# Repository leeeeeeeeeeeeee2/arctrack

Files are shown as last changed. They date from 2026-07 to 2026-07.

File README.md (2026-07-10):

# ArcTrack — Model Rocket Flight Computer

**ArcTrack** is a compact flight computer for model rockets. It logs altitude and
motion to a microSD card, reads GPS, and lets you **live-track the rocket over
WiFi** from your phone. v1.3 adds a power LED, buzzer, and servo header for
nose-cone parachute deploy at apogee.

Designed for a **BT-70** body tube with a 3D-printed nose avionics bay.

**Hardware:** bare **ESP32-C3FH4** (QFN-32, 4MB flash) + 2.4 GHz chip antenna,
USB-C, LiPo charger, 3.3 V regulator, BMP280, MPU-6050, microSD, GPS header,
servo + 5 V boost.

> RF note: chip-antenna matching may need tuning. See `hardware/DESIGN.md`.

## Features

- **Altitude** — BMP280 barometer + apogee detection  
- **Motion** — MPU-6050 IMU (launch / burnout)  
- **GPS** — ATGM336H (UART)  
- **Logging** — microSD CSV  
- **Live tracking** — WiFi AP + phone web dashboard  
- **USB-C** — charge + program (native USB)  
- **1S LiPo** — TP4056 charging  
- **Power LED** — on whenever the board is powered  
- **Buzzer** — beeps (apogee / status)  
- **Servo** — parachute / nose deploy at apogee (5 V boost on board)

## Repo layout

| Path | What |
|---|---|
| `hardware/DESIGN.md` | Electrical design, pinout, power, layout |
| `hardware/BOM.md` | Bill of materials |
| `hardware/WIRING.md` | Pin-by-pin wiring |
| `hardware/kicad/` | PCB project (schematic + board) |
| `hardware/gerbers/` | Fabrication outputs (when exported) |
| `firmware/` | PlatformIO firmware for ESP32-C3 |

## PCB / order

1. Read `hardware/DESIGN.md` and `hardware/WIRING.md`
2. Open the project in `hardware/kicad/`
3. Order boards from **JLCPCB** (4-layer, ~70×40 mm). Use Gerbers from `hardware/gerbers/` when present.
4. Hand-solder: GPS module, battery connector, switch, servo header as needed

## Firmware

```bash
cd firmware
pio run                 # build
pio run -t upload       # flash over USB-C
pio device monitor      # serial logs
```

Phone: join WiFi **`ArcTrack`** / password **`launch123`**, open **http://192.168.4.1**

### Pin map (firmware)

| Function | GPIO |
|---|---|
| I2C SDA / SCL | 4 / 5 |
| SD SCK / MOSI / MISO / CS | 6 / 7 / 3 / 10 |
| GPS RX / TX | 20 / 21 |
| Buzzer | 0 |
| Servo PWM | 1 |
| Power LED | hardwired to 3.3 V (not a GPIO) |

## Author

Leighton — UK maker / rocketry + electronics builds.

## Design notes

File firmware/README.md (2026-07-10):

# ArcTrack firmware (ESP32-C3)

PlatformIO project. Matches the ArcTrack PCB pinout in `../hardware/`.

## Build / flash

```bash
pio run
pio run -t upload
pio device monitor
```

## WiFi dashboard

- SSID: `ArcTrack`
- Password: `launch123`
- URL: http://192.168.4.1

## Pins

| Function | GPIO |
|---|---|
| SDA / SCL | 4 / 5 |
| SD SCK / MOSI / MISO / CS | 6 / 7 / 3 / 10 |
| GPS RX / TX | 20 / 21 |
| Buzzer | 0 |
| Servo | 1 |

Tune `servoStow()` / `servoDeploy()` pulse widths in `src/main.cpp` for your nose linkage.

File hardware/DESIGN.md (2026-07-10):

# RocketFC — Hardware Design (bare ESP32-C3FH4 + chip antenna)

Full bare-chip flight computer. Everything the SuperMini gave us for free
(regulator, USB, buttons, reset) is now on our board, plus the RF section
(crystal + antenna + matching). Keep this open while working in KiCad.

> **RF WARNING:** the antenna matching network usually needs tuning to work well,
> ideally with a VNA. To de-risk, copy component **values and layout** from
> Espressif's *ESP32-C3 Hardware Design Guidelines* reference schematic + the
> ESP32-C3-MINI-1 module schematic. Those are the known-good source of truth.

## 0. Main chip

Use **ESP32-C3FH4** (QFN-32, 5×5mm) — it has **4MB flash built in**, so no
external flash chip needed. (ESP32-C3FN4 is the same idea.)

Wire by **pin NAME** using the KiCad symbol — pin numbers vary, names don't.

## 1. Power

```
USB-C VBUS(5V) --> TP4056 --> LiPo(BAT) --> SW1 --> LDO(3.3V) --> +3V3 rail
                     |                                   (ME6211C33 / AMS1117)
                   charge
```

- **USB-C**: VBUS→5V net; GND→GND; D+→GPIO19; D−→GPIO18; CC1,CC2 each 5.1kΩ→GND.
- **TP4056**: IN←VBUS; BAT↔LiPo+; PROG→12kΩ→GND (~100mA); CE→IN; GND→GND.
- **SW1** slide switch: LiPo+ → LDO input (arms logic; charger stays on the cell).
- **LDO**: prefer **ME6211C33M5** (SOT-23-5, 150mV dropout — good at low LiPo V)
  over AMS1117 (1.1V dropout). IN←switched battery; OUT→+3V3; EN→IN; 1µF in, 1µF+
  10µF out.
- Bulk: 10µF on VBUS, 10µF on battery, 22µF on +3V3.

## 2. ESP32-C3FH4 core wiring

### Supply pins (all to +3V3, each with its own 100nF)
- `VDD3P3` (all instances) → +3V3, 100nF each
- `VDD3P3_CPU` → +3V3, 100nF
- `VDD3P3_RTC` → +3V3, 100nF
- `VDDA` / analog VDD3P3 → +3V3 via a **small ferrite bead / 0Ω** for RF cleanliness,
  then 100nF + 10µF (see reference)
- `VDD_SPI` → **1µF to GND** (internal LDO output for in-package flash; do NOT tie
  to 3V3 — follow reference)
- EP (exposed pad) → GND (stitch with vias)

### Enable / reset
- `CHIP_EN` (EN) → 10kΩ pull-up to +3V3, **1µF** to GND (reset RC).
- Optional **RESET button**: EN → button → GND.

### Strapping pins (critical for boot)
- `GPIO2` → 10kΩ pull-up to +3V3 (must be high at boot; keep nothing pulling it low)
- `GPIO8` → 10kΩ pull-up to +3V3 (must be high at boot)
- `GPIO9` → 10kΩ pull-up to +3V3 + **BOOT button** to GND (hold low at reset = flash mode)

### USB (native — no USB-UART chip)
- `GPIO18` → USB_D−
- `GPIO19` → USB_D+
- (optional USBLC6-2 ESD device on D+/D−)

### Clock
- 40 MHz crystal between `XTAL_P` and `XTAL_N`.
- Two load caps to GND (start ~**10–12pF** each; exact value = 2×(CL−Cstray),
  from the crystal datasheet). Some designs also add a small series R (~0Ω).

## 3. RF section (antenna + matching) — copy the reference!

- `LNA_IN` (RF pin) → **pi-matching network** → 50Ω feed line → **chip antenna**.
- Pi network = 3 footprints: shunt C1 (to GND), series L, shunt C2 (to GND).
  Start with **L = series 0Ω/2.7nH, C1/C2 = unpopulated (DNP)**, then tune. Use
  the antenna vendor's app note values as the starting point.
- **Chip antenna**: e.g. Johanson 2450AT18A100 or similar 2.4GHz ceramic. Follow
  its datasheet **ground keep-out** exactly (a copper-free region under/around it).
- **50Ω trace**: keep short; on 1.6mm 2-layer FR4 a top trace over the ground
  plane ≈ 2.9mm wide for 50Ω (use KiCad's calculator with your stackup).
- Nothing (no copper/ground pour) under the antenna keep-out.

## 4. Pin assignments (peripherals — same as before, firmware unchanged)

| Function | Signal | GPIO  | Notes |
|---|---|---|---|
| I2C data | SDA | GPIO4 | BMP280 + MPU-6050 |
| I2C clock | SCL | GPIO5 | |
| SD clock | SPI_SCK  | GPIO6 | |
| SD data out | SPI_MOSI | GPIO7 | |
| SD data in | SPI_MISO | GPIO3 | |
| SD chip select  | SD_CS | GPIO10| |
| GPS → ESP | UART1_RX | GPIO20| |
| ESP → GPS | UART1_TX | GPIO21| |
| USB D− | — | GPIO18| native USB |
| USB D+ | — | GPIO19| native USB |
| Status LED | LED | GPIO8 | LED+220Ω to +3V3 (also strapping-pulled high) |

## 5. Sensors (bare chips) — you've already wired most of this

### I2C pull-ups
- 4.7kΩ from SDA→+3V3 and SCL→+3V3.

### BMP280
- VDD (8)→+3V3 (100nF), VDDIO (6)→+3V3 (100nF), GND (1)→GND, GND (7)→GND
- SDI (5)→SDA, SCK (4)→SCL, SDO (3)→GND (0x76), CSB (2)→+3V3 (I2C mode)

### MPU-6050
- VDD (13)→+3V3 (100nF), VLOGIC (8)→+3V3 (10nF), GND (18)→GND
- REGOUT (10)→100nF to GND (REQUIRED), CPOUT (20)→2.2nF to GND (REQUIRED)
- SDA (24)→SDA, SCL (23)→SCL, AD0 (9)→GND (0x68)
- FSYNC (11)→GND, CLKIN (1)→GND
- INT (12), AUX_DA (6), AUX_CL (7) → No-Connect

## 6. microSD (SPI)
- VDD→+3V3 (10µF), GND→GND
- CLK→SPI_SCK, CMD→SPI_MOSI, DAT0→SPI_MISO, DAT3→SD_CS
- 10kΩ pull-ups on MISO and CS.

## 7. GPS (ATGM336H, 4-pin header)
- VCC→+3V3 (10µF), GND→GND, module TX→GPIO20, module RX→GPIO21.

## 8. Layout / routing notes (RF matters now)
- **Antenna at a board edge/corner**, its keep-out zone kept 100% copper-free
  (no ground pour, no traces). Everything else stays away from it.
- Solid **ground plane** on the opposite layer; stitch the chip's EP and grounds
  with lots of vias.
- Keep the **40MHz crystal** right next to the chip, short traces, guarded by
  ground, load caps close.
- Keep the **RF trace** (LNA_IN → antenna) short, 50Ω, over unbroken ground.
- Decoupling caps hug each supply pin; analog supply gets the ferrite + extra cap.
- Route USB D+/D− as a short, equal-length differential pair.
- BMP280 gets air (vent, not sealed); MPU-6050 near the rocket's center axis.

## 9. Firmware pin defines (unchanged)
```cpp
#define PIN_SDA     4
#define PIN_SCL     5
#define PIN_SD_SCK  6
#define PIN_SD_MOSI 7
#define PIN_SD_MISO 3
#define PIN_SD_CS   10
#define PIN_GPS_RX  20
#define PIN_GPS_TX  21
#define PIN_LED     8
```

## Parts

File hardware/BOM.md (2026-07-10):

# RocketFC — Bill of Materials (bare ESP32-C3FH4)

Full bare-chip board. More parts than the module version, and it includes the RF
section (crystal + chip antenna + matching).

> LCSC/JLCPCB `C#######` codes drift — treat as starting points. Prefer **Basic**
> parts, confirm footprints. Copy RF/crystal values from Espressif's ESP32-C3
> reference schematic.

## JLCPCB assembly (SMD)

| Ref | Part | Value / Pkg | Suggested LCSC | Notes |
|-----|---|---|---|---|
| U1  | ESP32-C3FH4 | QFN-32, 4MB flash | C3013796 | main chip (or ESP32-C3FN4) |
| U2  | BMP280 | LGA-8 | C90293 | barometer |
| U3  | MPU-6050 | QFN-24 | C24112 | IMU |
| U4  | ME6211C33M5 | SOT-23-5 | C82942 | 3V3 LDO (low dropout) |
| U5  | TP4056 | ESOP-8 | C16581 | 1S charger |
| U6  | USBLC6-2SC6 | SOT-23-6 | C7519 | USB ESD (optional) |
| Y1  | 40 MHz crystal | 3225 SMD | C9002 | check load cap CL |
| ANT1| 2.4GHz ceramic chip antenna | e.g. 2450AT18A100 | C731332 | follow keep-out |
| J1  | USB-C receptacle | 16P SMD | (pick one) | prog + charge |
| J-SD| microSD socket | push-pull SMD | C91145 | check footprint |
| SW2 | RESET button | SMD tact | C318884 | optional |
| SW3 | BOOT button | SMD tact | C318884 | flash mode |
| L1  | RF match series | 2.7nH 0402 | tune | pi-network (start here) |
| L2  | analog supply | ferrite bead 0402 | C1015 | or 0Ω |
| Cx1,Cx2 | crystal load caps | ~10–12pF 0402 | C1653 | from crystal CL |
| Cm1,Cm2 | RF match shunts | DNP 0402 | — | populate when tuning |
| R1,R2 | I2C pull-ups | 4.7k 0402 | C25900 | SDA/SCL |
| R3,R4 | SD pull-ups | 10k 0402 | C25744 | MISO/CS |
| R5,R6,R7 | strapping pull-ups | 10k 0402 | C25744 | GPIO2/8/9 |
| R8  | EN pull-up | 10k 0402 | C25744 | reset |
| R9,R10 | USB CC | 5.1k 0402 | C25905 | CC1/CC2 |
| R11 | TP4056 PROG | 12k 0402 | C25744 | ~100mA |
| R12 | LED | 220R 0402 | C25808 | status LED |
| C-vdd | ESP decoupling | 100nF 0402 ×~6 | C1525 | one per supply pin |
| C-en | EN cap | 1µF 0402 | C15849 | reset RC |
| C-spi | VDD_SPI | 1µF 0402 | C15849 | |
| C-bmp | BMP decoupling | 100nF 0402 ×2 | C1525 | VDD, VDDIO |
| C-mpu1| MPU VDD | 100nF 0402 | C1525 | |
| C-mpu2| MPU REGOUT | 100nF 0402 | C1525 | |
| C-mpu3| MPU VLOGIC | 10nF 0402 | C1546 | |
| C-mpu4| MPU CPOUT | 2.2nF 0402 | C1548 | |
| C-bulk| bulk | 10µF 0805 ×3 | C15850 | VBUS/BAT/GPS/SD |
| C-3v3 | 3V3 bulk | 22µF 0805 | C45783 | LDO out |
| D1  | status LED | 0402 | C2286 | |

## Hand-solder

| Ref | Part | Notes |
|-----|---|---|
| J2  | JST PH 2.0mm 2-pin | battery |
| J3  | 4-pin header 2.54mm | GPS: VCC/GND/TX/RX |
| SW1 | slide switch | power arm |
| — | ATGM336H GPS module | UART |
| — | 1S LiPo (402035 200mAh) + JST | battery |

## Reality note
This is ~35+ parts vs ~10 for the SuperMini carrier, and the RF section can need
tuning. Budget extra board revisions. If it powers on but WiFi won't connect,
suspect the antenna/matching first.

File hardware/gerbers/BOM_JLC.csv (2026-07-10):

Comment | Designator | Footprint | LCSC Part #
GPS HEADERS | J4 | PinHeader_1x04_P2.54mm_Vertical
Micro_SD_Card | J3 | microSD_HC_Hirose_DM3AT-SF-PEJM5
Antenna | AE1 | Johanson_2450AT43F0100
12k | R7 | R_0402_1005Metric
10k | R1,R2,R3,R4,R10,R11 | R_0402_1005Metric
100n | C1,C2,C4,C5,C7,C8,C9,C10 | C_0402_1005Metric
JST BATTERY CONNECTOR | J2 | JST_PH_B2B-PH-K_1x02_P2.00mm_Vertical
2.7nH | L1 | L_0402_1005Metric
AMS REG | U3 | SOT-223-3_TabPin2
4.7k | R8,R9 | R_0402_1005Metric
1p | C19,C20 | C_0402_1005Metric
40MHz | Y1 | Crystal_SMD_2012-2Pin_2.0x1.2mm
5.1k | R5,R6 | R_0402_1005Metric
1u | C11,C12 | C_0402_1005Metric
10u | C16,C17,C18 | C_0805_2012Metric
22u | C15 | C_0805_2012Metric
2.2n | C6 | C_0402_1005Metric
10p | C13,C14 | C_0402_1005Metric
10n | C3 | C_0402_1005Metric
TP4056 | U5 | SOIC-8-1EP_3.9x4.9mm_P1.27mm_EP2.41x3.3mm_ThermalVias
USBC CHARGE PORT | J1 | USB_C_Receptacle_HRO_TYPE-C-31-M-12
POWER SWITCH | SW1 | SW_SPDT_PCM12
BMP280 | U2 | Bosch_LGA-8_2x2.5mm_P0.65mm_ClockwisePinNumbering
ESP32-C3FH4 | U4 | QFN-32-1EP_5x5mm_P0.5mm_EP3.7x3.7mm
MPU-6050 | U1 | InvenSense_QFN-24_4x4mm_P0.5mm
SERVO 5V BOOST | U6 | SOT-23-6
330 | R12 | R_0402_1005Metric
2.2uH | L2 | L_0402_1005Metric
100k | R14 | R_0402_1005Metric
SERVO | J5 | PinHeader_1x03_P2.54mm_Vertical
100uF | C23 | C_0805_2012Metric
10uF | C21,C22 | C_0805_2012Metric
Buzzer | BZ1 | Buzzer_Mallory_AST1109MLTRQ
LED | D1 | LED_0402_1005Metric
510k | R13 | R_0402_1005Metric

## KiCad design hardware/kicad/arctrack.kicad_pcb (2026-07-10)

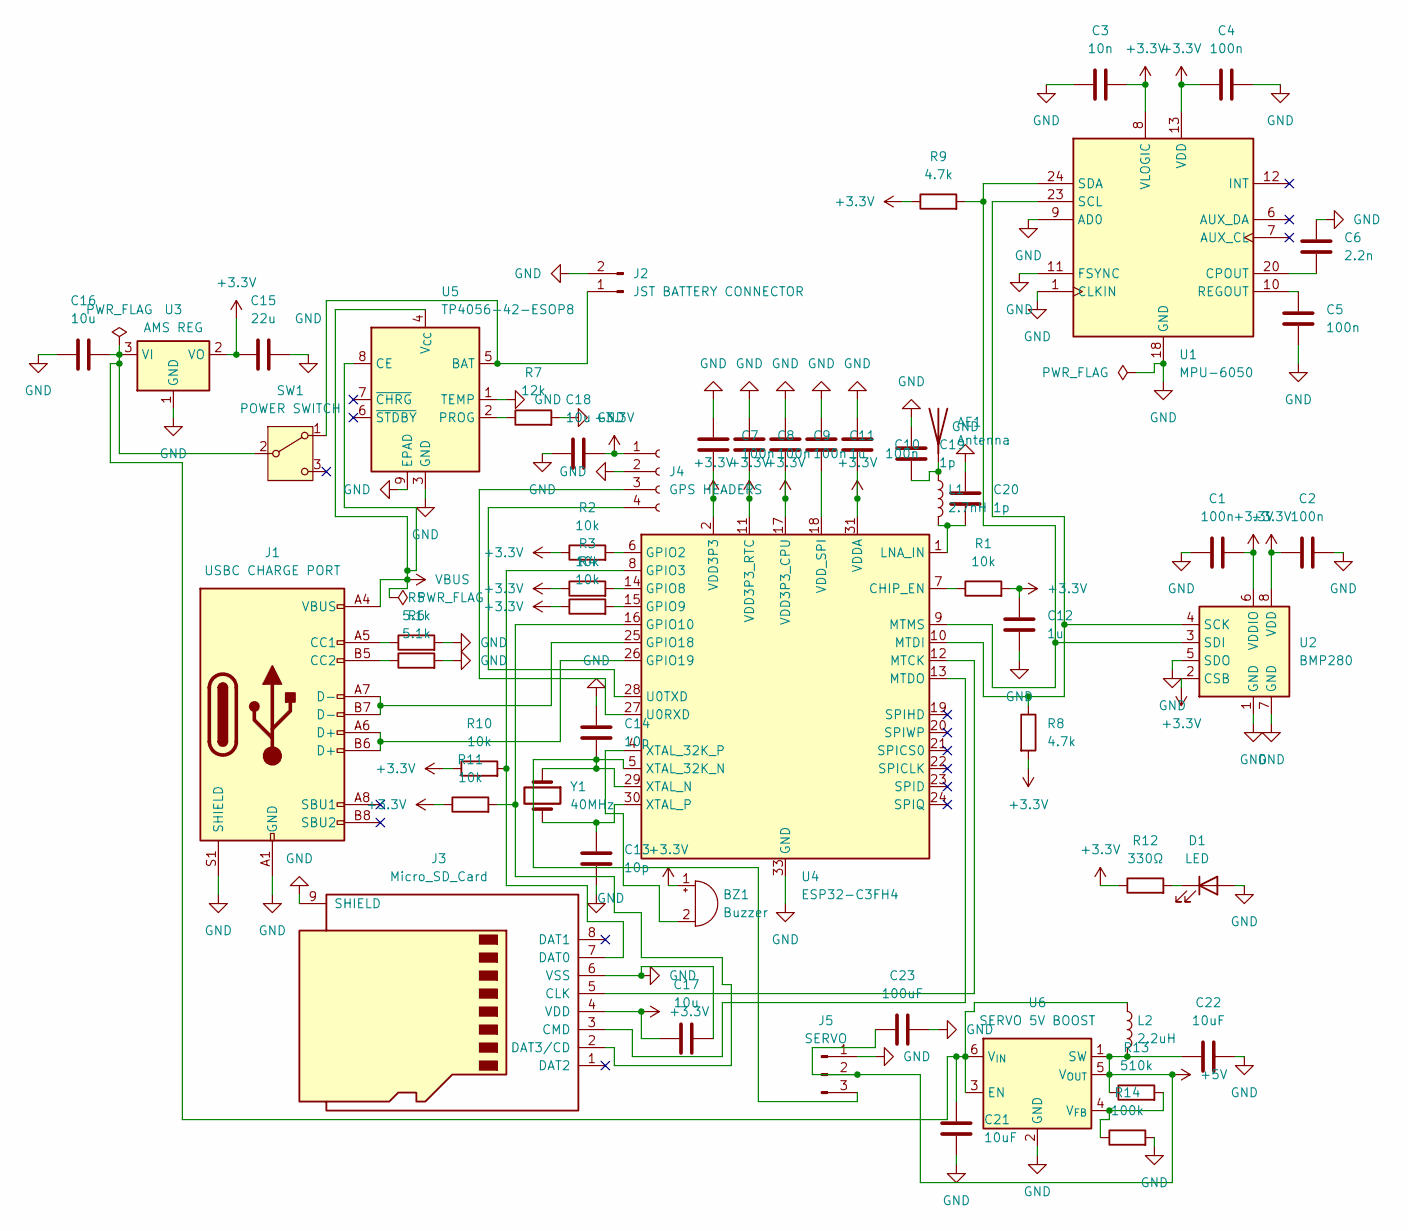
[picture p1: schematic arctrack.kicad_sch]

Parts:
AE1: Antenna; Johanson_2450AT43F0100
BZ1: Buzzer; Buzzer_Mallory_AST1109MLTRQ
C1, C2, C4, C5, C7, C8, C9, C10: 100n; C_0402_1005Metric
C3: 10n; C_0402_1005Metric
C6: 2.2n; C_0402_1005Metric
C11, C12: 1u; C_0402_1005Metric
C13, C14: 10p; C_0402_1005Metric
C15: 22u; C_0805_2012Metric
C16, C17, C18: 10u; C_0805_2012Metric
C19, C20: 1p; C_0402_1005Metric
C21, C22: 10uF; C_0805_2012Metric
C23: 100uF; C_0805_2012Metric
D1: LED; LED_0402_1005Metric
J1: USBC CHARGE PORT; USB_C_Receptacle_HRO_TYPE-C-31-M-12
J2: JST BATTERY CONNECTOR; JST_PH_B2B-PH-K_1x02_P2.00mm_Vertical
J3: Micro_SD_Card; microSD_HC_Hirose_DM3AT-SF-PEJM5
J4: GPS HEADERS; PinHeader_1x04_P2.54mm_Vertical
J5: SERVO; PinHeader_1x03_P2.54mm_Vertical
L1: 2.7nH; L_0402_1005Metric
L2: 2.2uH; L_0402_1005Metric
R1, R2, R3, R4, R10, R11: 10k; R_0402_1005Metric
R5, R6: 5.1k; R_0402_1005Metric
R7: 12k; R_0402_1005Metric
R8, R9: 4.7k; R_0402_1005Metric
R12: 330Ω; R_0402_1005Metric
R13: 510k; R_0402_1005Metric
R14: 100k; R_0402_1005Metric
SW1: POWER SWITCH; SW_SPDT_PCM12
U1: MPU-6050; InvenSense_QFN-24_4x4mm_P0.5mm
U2: BMP280; Bosch_LGA-8_2x2.5mm_P0.65mm_ClockwisePinNumbering
U3: AMS REG; SOT-223-3_TabPin2
U4: ESP32-C3FH4; QFN-32-1EP_5x5mm_P0.5mm_EP3.7x3.7mm
U5: TP4056-42-ESOP8; SOIC-8-1EP_3.9x4.9mm_P1.27mm_EP2.41x3.3mm_ThermalVias
U6: SERVO 5V BOOST; SOT-23-6
Y1: 40MHz; Crystal_SMD_2012-2Pin_2.0x1.2mm

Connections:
+3.3V: BZ1.1 (+), C1.2, C2.1, C3.2, C4.1, C7.2, C8.2, C9.2, C10.2, C12.1, C15.1, C17.1, C18.2, J3.4 (VDD), J4.1, R1.2, R2.1, R3.1, R4.1, R8.2, R9.1, R10.1, R11.1, R12.1, U1.8 (VLOGIC), U1.13 (VDD), U2.2 (CSB), U2.6 (VDDIO), U2.8 (VDD), U3.2 (VO), U4.2 (VDD3P3), U4.3 (VDD3P3), U4.11 (VDD3P3_RTC), U4.17 (VDD3P3_CPU), U4.31 (VDDA), U4.32 (VDDA)
+5V: C22.1, C23.1, J5.2, L2.2, R13.1, U6.1 (SW), U6.5 (V_{OUT})
GND: C1.1, C2.2, C3.1, C4.2, C5.2, C6.1, C7.1, C8.1, C9.1, C10.1, C11.1, C12.2, C13.2, C14.1, C15.2, C16.1, C17.2, C18.1, C19.1, C20.2, C21.1, C22.2, C23.2, D1.2 (A), J1.A1 (GND), J1.A12 (GND), J1.B1 (GND), J1.B12 (GND), J1.S1 (SHIELD), J2.2, J3.6 (VSS), J3.9 (SHIELD), J4.2, J5.1, R5.2, R6.2, R7.2, R14.2, U1.1 (CLKIN), U1.9 (AD0), U1.11 (FSYNC), U1.18 (GND), U2.1 (GND), U2.5 (SDO), U2.7 (GND), U3.1 (GND), U4.33 (GND), U5.1 (TEMP), U5.3 (GND), U5.9 (EPAD), U6.2 (GND)
unnamed: AE1.1 (A), C19.2, L1.1
unnamed: BZ1.2 (-), U4.4 (XTAL_32K_P)
unnamed: D1.1 (K), R12.2
unnamed: J1.A5 (CC1), R5.1
unnamed: J1.B5 (CC2), R6.1
unnamed: J2.1, SW1.1 (A), U5.5 (BAT)
unnamed: J3.5 (CLK), U4.12 (MTCK)
unnamed: J3.3 (CMD), U4.13 (MTDO)
unnamed: J3.7 (DAT0), R10.2, U4.8 (GPIO3)
unnamed: J3.2 (DAT3/CD), R11.2, U4.16 (GPIO10)
unnamed: J4.3, U4.27 (U0RXD)
unnamed: J4.4, U4.28 (U0TXD)
unnamed: C14.2, J5.3, U4.5 (XTAL_32K_N), U4.29 (XTAL_N), Y1.1
unnamed: C16.2, C21.2, L2.1, SW1.2 (B), U3.3 (VI), U6.3 (EN), U6.6 (V_{IN})
unnamed: C6.2, U1.20 (CPOUT)
unnamed: C5.1, U1.10 (REGOUT)
unnamed: R8.1, U1.23 (SCL), U2.4 (SCK), U4.10 (MTDI)
unnamed: R9.2, U1.24 (SDA), U2.3 (SDI), U4.9 (MTMS)
unnamed: R1.1, U4.7 (CHIP_EN)
unnamed: R2.2, U4.6 (GPIO2)
unnamed: R3.2, U4.14 (GPIO8)
unnamed: R4.2, U4.15 (GPIO9)
unnamed: J1.A7 (D-), J1.B7 (D-), U4.25 (GPIO18)
unnamed: J1.A6 (D+), J1.B6 (D+), U4.26 (GPIO19)
unnamed: C20.1, L1.2, U4.1 (LNA_IN)
unnamed: C11.2, U4.18 (VDD_SPI)
unnamed: C13.1, U4.30 (XTAL_P), Y1.2
unnamed: R7.1, U5.2 (PROG)
unnamed: R13.2, R14.1, U6.4 (V_{FB})
VBUS: J1.A4 (VBUS), J1.A9 (VBUS), J1.B4 (VBUS), J1.B9 (VBUS), U5.4 (V_{CC}), U5.8 (CE)

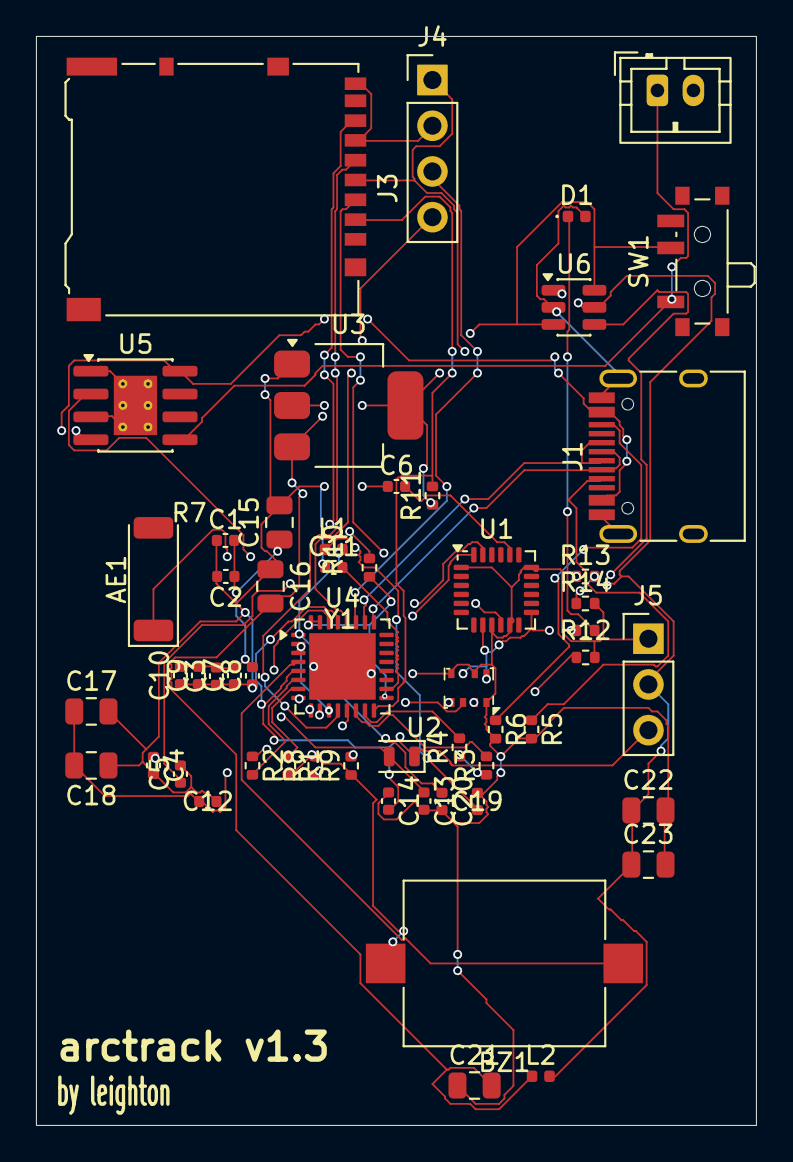
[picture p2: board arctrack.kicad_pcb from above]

Board: 4 copper layers, 40.0 x 60.5 mm, 55 parts (0 on the bottom side), 33 nets.

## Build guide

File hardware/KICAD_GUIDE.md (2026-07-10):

# RocketFC — KiCad 9 Step-by-Step (beginner)

Follow this in order. Keep `DESIGN.md` open in another window — it's the source of
truth for every connection. Don't rush; expect this to take a few sessions.

Big picture, there are 5 phases:
1. Draw the **schematic** (logical wiring)
2. Assign **footprints** (physical shape of each part)
3. Lay out + **route** the board
4. Run **DRC** (error check)
5. Export **manufacturing files** for JLCPCB

---

## Phase 0 — Create the project
1. Open **KiCad**.
2. `File → New Project`. Make a folder `RocketFC`, name the project `RocketFC`, Save.
3. Double-click `RocketFC.kicad_sch` to open the **Schematic Editor**.

---

## Phase 1 — Schematic (the logical wiring)

You place a symbol for each part, then draw wires between pins per `DESIGN.md`.

### 1a. Place symbols
- Press **A** (Add Symbol). Search and place each of these. If an exact name
  isn't found, use the closest match — the electrical connections matter, not the
  symbol's cosmetic name.

This is the **bare ESP32-C3FH4** parts list (see `DESIGN.md` + `BOM.md`).

| Search for | Qty | It's the… |
|---|-----|---|
| `ESP32-C3` | 1 | main chip — pick the bare **ESP32-C3FH4/FN4** (QFN-32), NOT the -MINI module |
| `BMP280` | 1 | barometer |
| `MPU-6050` | 1 | IMU |
| `microSD` | 1 | SD socket |
| `Crystal_GND` | 1 | 40MHz crystal (4-pad) |
| `Antenna` | 1 | chip antenna (or a generic 1-pin `Antenna` symbol) |
| `L` | 1 | RF series match / ferrite |
| `ME6211` or `AP2112` / `AMS1117` | 1 | 3.3V LDO |
| `TP4056` | 1 | charger |
| `USB_C_Receptacle_USB2.0` | 1 | USB-C |
| `USBLC6-2SC6` | 1 | USB ESD (optional) |
| `SW_Push` | 2 | RESET + BOOT buttons |
| `Conn_01x02` | 1 | battery JST |
| `Conn_01x04` | 1 | GPS header |
| `SW_SPDT` | 1 | slide switch |
| `R` | ~12 | resistors (see BOM) |
| `C` | ~20 | capacitors (see BOM) |

If the bare `ESP32-C3FH4` symbol isn't in your KiCad libraries, you may need to
add Espressif's library or grab the symbol from the manufacturer/SnapEDA. Tell me
if it's missing and we'll sort it.

Tips: **M** = move, **R** = rotate, **Esc** = cancel, mouse-wheel = zoom.

### 1b. Add power symbols
- Press **P** (Add Power). Place several **GND**, **+3V3**, and one **VBUS**(+5V)
  and **VBAT** symbol. These are how you connect grounds/power without drawing
  wires all across the sheet — every `GND` symbol is the same net automatically.

### 1c. Set resistor/cap values
- Hover a part, press **E** (Edit), set the Value (e.g. `4.7k`, `100n`, `22u`).
  Match the values in `DESIGN.md` / `BOM.md`.

### 1d. Wire it up
- Press **W** to draw a wire from pin to pin. Follow the **netlist table** in
  `DESIGN.md` section 5. Work one block at a time:
  1. SuperMini headers: wire 5V, GND, 3V3 and each GPIO to its net (§3/§5).
  2. Power: battery JST+ → switch → Schottky D1 → SuperMini 5V pin; JST− → GND.
  3. I2C: SDA/SCL with the two 4.7k pull-ups; BMP280 + MPU-6050 + 100nF each.
  4. SPI: microSD (4 signals + 2× 10k pull-ups + 10µF).
  5. Header: GPS (VCC/GND/TX/RX + 10µF).
- For messy long connections, use **labels** instead of wires: press **L**, type a
  net name (e.g. `SDA`), and stick it on a pin. Two pins with the same label name
  are connected. This keeps the sheet clean.

### 1e. Annotate + check
- Top toolbar: **Annotate Schematic** (gives parts R1, C1, U1… numbers).
- Run **ERC** (Electrical Rules Check). Fix real errors (unconnected pins,
  power not driven). Some warnings are OK; read them.

---

## Phase 2 — Assign footprints (physical shapes)
1. Tools → **Assign Footprints** (or the footprint-assignment button).
2. For each symbol pick the footprint from `BOM.md`. Common ones:
   - Resistors/caps → `R_0402_1005Metric` / `C_0402_1005Metric` for smallest
     (use `_0603_1608Metric` if you'd rather hand-solder them).
   - SuperMini rows → `PinSocket_1x08_P2.54mm_Vertical` (×2) if using female
     sockets (your SuperMini has male pins), or `PinHeader_1x08...` if soldering
     flat. Measure the spacing between your SuperMini's two rows and set the two
     connectors that far apart.
   - Schottky D1 → `D_SOD-123`.
   - GPS header / JST → 2.54mm header / JST PH footprints.
3. **For JLCPCB assembly**: for each SMD part JLC will solder, add a field named
   **`LCSC`** with the part number from `BOM.md` (Edit symbol → add field
   `LCSC` = e.g. `C6186`). This is what lets JLC auto-source the part. The
   easiest path is installing the **"JLCPCB Fabrication Toolkit"** plugin later —
   it reads these fields.

---

## Phase 3 — Layout & route the board
1. Back in the Schematic Editor: **Tools → Update PCB from Schematic** (F8).
   This opens the **PCB Editor** with all parts stacked together, connected by
   thin "ratsnest" lines. (This step replaces manually importing a netlist.)
2. **Board outline**: select the **Edge.Cuts** layer, draw a rectangle the size
   of your payload bay (e.g. 25×50 mm). Add mounting holes if you want.
3. **Place parts** (press M to move) sensibly:
   - ESP32-C3 **antenna at a board edge**, nothing under it.
   - USB-C at one end, battery JST/switch at the other.
   - Sensors central-ish; BMP280 where air can reach it.
4. **Route**: press **X** and click pin-to-pin to draw copper traces, following
   the ratsnest. Use the bottom layer (F.Cu/B.Cu) as needed; add **vias** (V) to
   switch layers. Keep power traces a bit wider (e.g. 0.4mm).
5. **Ground pour**: draw a filled zone on both copper layers tied to **GND**
   (Add Filled Zone), then **B** to fill. This makes grounding easy — keep it
   OUT of the antenna keep-out area.

---

## Phase 4 — Check it
- Run **DRC** (Design Rules Check). Fix any clearance/unrouted errors until it's
  clean (or only harmless warnings remain).

---

## Phase 5 — Export for JLCPCB
Easiest: install the **JLCPCB Fabrication Toolkit** plugin — one click makes the
Gerbers, BOM, and placement (CPL) files. Manual way:
1. `File → Fabrication Outputs → Gerbers (.gbr)` → export all layers → **zip** them.
2. `File → Fabrication Outputs → Drill Files` → add to the zip.
3. `File → Fabrication Outputs → Component Placement (.pos)` → CPL file.
4. Schematic Editor: `Tools → Generate BOM` → the BOM (with your `LCSC` column).
5. On jlcpcb.com: upload the Gerber zip, turn on **SMT Assembly**, upload the BOM
   + CPL, match/confirm each part, review the render, order.

---

## When you're stuck
KiCad has a curve — getting stuck is normal. Tell me which **phase and step**
you're on and what you see, and I'll walk you through that specific bit. Common
first snags: a symbol not found (use nearest match), ERC "power not driven"
(add a `PWR_FLAG` on your +3V3/VBUS/GND nets), or footprints not matching pins.

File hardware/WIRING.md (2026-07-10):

# RocketFC — Exact pin-by-pin wiring (bare ESP32-C3FH4)

Pin numbers below match the KiCad symbols in the current schematic
(U4 = ESP32-C3FH4, U1 = MPU-6050, U2 = BMP280).

"100nF→GND" etc. means: put that cap with one leg on this pin's net and the other
leg on GND, right next to the pin.

Confusing-but-important: on the ESP32-C3, `MTMS/MTDI/MTCK/MTDO` = GPIO4/5/6/7.

---

## U4 — ESP32-C3FH4

| Pin | Symbol name | Connect to |
|-----|---|---|
| 1  | LNA_IN | RF: → matching network → antenna |
| 2  | VDD3P3 | **+3V3** + 100nF→GND |
| 4  | XTAL_32K_P (GPIO0) | **BZ1 −** (buzzer, v1.1) |
| 5  | XTAL_32K_N (GPIO1) | **J5 pin 3** (servo signal, v1.1) |
| 6  | GPIO2 | 10k→**+3V3** (strapping, must be high at boot) |
| 7  | CHIP_EN | 10k→**+3V3**, 1µF→GND, RESET button→GND |
| 8  | GPIO3 | **SD MISO** (U-SD pin DAT0) + 10k→+3V3 |
| 9  | MTMS (GPIO4) | **SDA** |
| 10 | MTDI (GPIO5) | **SCL** |
| 11 | VDD3P3_RTC | **+3V3** + 100nF→GND |
| 12 | MTCK (GPIO6) | **SD SCK** (U-SD pin CLK) |
| 13 | MTDO (GPIO7) | **SD MOSI** (U-SD pin CMD) |
| 14 | GPIO8 | 10k→+3V3 (strapping only — no LED here in v1.1) |
| 15 | GPIO9 | 10k→**+3V3** + BOOT button→GND |
| 16 | GPIO10 | **SD CS** (U-SD pin DAT3) |
| 17 | VDD3P3_CPU | **+3V3** + 100nF→GND |
| 18 | VDD_SPI | **1µF→GND ONLY** (do not tie to +3V3) |
| 19 | SPIHD | **No-Connect (Q)** — internal flash |
| 20 | SPIWP | **No-Connect (Q)** |
| 21 | SPICS0 | **No-Connect (Q)** |
| 22 | SPICLK | **No-Connect (Q)** |
| 23 | SPID | **No-Connect (Q)** |
| 24 | SPIQ | **No-Connect (Q)** |
| 25 | GPIO18 | **USB D−** |
| 26 | GPIO19 | **USB D+** |
| 27 | U0RXD (GPIO20) | **GPS module TX** |
| 28 | U0TXD (GPIO21) | **GPS module RX** |
| 29 | XTAL_N | 40MHz crystal + ~10pF load cap→GND *(confirm pin #)* |
| 30 | XTAL_P | 40MHz crystal + ~10pF load cap→GND *(confirm pin #)* |
| 31 | VDDA | **+3V3** (via ferrite bead / 0Ω) + 100nF→GND |
| 33 | GND (EP pad) | **GND** |

---

## v1.1 additions (ArcTrack — LED, buzzer, servo, 5 V boost)

Add these in the **same** KiCad project. Do **not** start a new one.

### D1 + R12 — power LED (always on when board is powered)

| Ref | Value | Footprint |
|-----|---|---|
| D1  | LED | `LED_SMD:LED_0402_1005Metric` |
| R12 | **330Ω** | `Resistor_SMD:R_0402_1005Metric` |

**Wire:** **+3V3 → R12 → D1 anode (+) → D1 cathode (−) → GND**

Not 330**k** — that would block almost all current and the LED would stay dark.

---

### BZ1 — buzzer

| Ref | Value | Footprint |
|-----|---|---|
| BZ1 | Active buzzer **3.3 V** SMD | pick to match LCSC part |

**Wire:**
- **+3V3 → BZ1 +**
- **BZ1 − → U4 pin 4** (XTAL_32K_P / GPIO0)

Remove any **No-Connect** flag on U4 pin 4 if you added one earlier.

---

### J5 — servo header (3-pin, 2.54 mm)

| Ref | Value | Footprint |
|-----|---|---|
| J5  | `Conn_01x03` | `Connector_PinHeader_2.54mm:PinHeader_1x03` |

| J5 pin | Net |
|---|-----|
| 1 | **GND** |
| 2 | **+5V** (servo power — from boost U6) |
| 3 | **U4 pin 5** (XTAL_32K_N / GPIO1) |

Remove any **No-Connect** on U4 pin 5.

---

### U6 — 5 V boost (servo power on the PCB)

Powers the servo only. Do **not** connect +5V to the ESP32.

| Ref | Value | Notes |
|-----|---|---|
| U6  | 5 V boost IC (e.g. TPS61223, FP6296) | SOT-23-6 + inductor per datasheet |
| L2  | **2.2 µH** | boost inductor |
| C21 | **100 µF** | +5V bulk, near J5 |
| C22 | **10 µF** | U6 input |
| C23 | **10 µF** | U6 output |

**Wire:**
- **U6 IN** → same net as **LDO input** (battery side **after SW1**)
- **U6 GND** → **GND**
- **U6 OUT** → **+5V** power symbol
- **+5V → J5 pin 2**
- **C21:** +5V ↔ GND near J5

Add a **+5V** power symbol (press **P**, search `+5V`).

---

### Board outline (PCB editor, after schematic)

- **Edge.Cuts:** **70 × 40 mm** rectangle (long side ≥ 70 mm → no JLC edge rails)
- **4×** `MountingHole_2.7mm` ~3 mm in from each corner

---

### Firmware pins (v1.1)

```cpp
#define PIN_BUZZER  0   // U4 pin 4
#define PIN_SERVO   1   // U4 pin 5
// Power LED is hardwired — no GPIO
```

---

## U1 — MPU-6050

| Pin | Name | Connect to |
|-----|---|---|
| 13 | VDD | **+3V3** + 100nF→GND |
| 8  | VLOGIC | **+3V3** + 10nF→GND |
| 18 | GND | **GND** |
| 24 | SDA | **SDA** (→ U4 pin 9) |
| 23 | SCL | **SCL** (→ U4 pin 10) |
| 9  | AD0 | **GND** (I2C address 0x68) |
| 11 | FSYNC  | **GND** |
| 1  | CLKIN  | **GND** |
| 10 | REGOUT | **100nF→GND** (required) |
| 20 | CPOUT  | **2.2nF→GND** (required) |
| 12 | INT | **No-Connect (Q)** |
| 6  | AUX_DA | **No-Connect (Q)** |
| 7  | AUX_CL | **No-Connect (Q)** |

---

## U2 — BMP280

| Pin | Name  | Connect to |
|-----|---|---|
| 8  | VDD | **+3V3** + 100nF→GND |
| 6  | VDDIO | **+3V3** + 100nF→GND |
| 1  | GND | **GND** |
| 7  | GND | **GND** |
| 5  | SDI | **SDA** (→ U4 pin 9) |
| 4  | SCK | **SCL** (→ U4 pin 10) |
| 3  | SDO | **GND** (I2C address 0x76) |
| 2  | CSB | **+3V3** (selects I2C mode — required) |

---

## The I2C bus + pull-ups (ties it all together)
- Net **SDA** = U4 pin 9 + U1 pin 24 + U2 pin 5 + one 4.7k resistor to +3V3
- Net **SCL** = U4 pin 10 + U1 pin 23 + U2 pin 4 + one 4.7k resistor to +3V3

Use **net labels** (press **L**, type `SDA` / `SCL`) on each of those pins instead
of drawing long wires — same label name = connected.

---

## Support parts still to place (then wire per above references)
- **40MHz crystal (Y1)** → U4 pins 29/30, load caps to GND
- **Chip antenna + matching (L,C,C)** → U4 pin 1 (LNA_IN)
- **RESET button** → U4 pin 7; **BOOT button** → U4 pin 15
- **USB-C (J1)** → U4 pins 25/26 (D−/D+), VBUS, GND, CC 5.1k×2
- **LDO (U-reg)** → makes +3V3
- **TP4056** → USB VBUS in, LiPo, PROG 12k
- **microSD, GPS header, JST, slide switch** → per tables above

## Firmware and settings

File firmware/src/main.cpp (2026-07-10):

// ArcTrack — ESP32-C3 model rocket flight computer
//
// - BMP280 barometer  -> altitude (relative to ground) + apogee detection
// - MPU-6050 IMU      -> accel/gyro, launch/burnout detection
// - ATGM336H GPS      -> lat/lon/alt/speed/sats (UART)
// - microSD           -> CSV flight log (SPI)
// - WiFi AP + web page -> live tracking from your phone
// - Buzzer (GPIO0) + servo (GPIO1) for apogee / nose deploy
//
// Pin map MUST match hardware/DESIGN.md / WIRING.md.

#include <Arduino.h>
#include <Wire.h>
#include <SPI.h>
#include <SD.h>
#include <WiFi.h>
#include <WebServer.h>
#include <Adafruit_BMP280.h>
#include <Adafruit_MPU6050.h>
#include <Adafruit_Sensor.h>
#include <TinyGPSPlus.h>
#include <math.h>

// ---------------------------------------------------------------- pins
#define PIN_SDA      4
#define PIN_SCL      5
#define PIN_SD_SCK   6
#define PIN_SD_MOSI  7
#define PIN_SD_MISO  3
#define PIN_SD_CS    10
#define PIN_GPS_RX   20   // ESP receives GPS TX here
#define PIN_GPS_TX   21   // ESP transmits to GPS RX
#define PIN_BUZZER   0    // active buzzer (low side)
#define PIN_SERVO    1    // parachute / nose deploy PWM
// Power LED is hardwired to +3V3 on the PCB (no GPIO)

// ---------------------------------------------------------------- config
static const char*    AP_SSID     = "ArcTrack";
static const char*    AP_PASS     = "launch123";   // >=8 chars
static const uint32_t GPS_BAUD    = 9600;          // ATGM336H default
static const uint32_t SAMPLE_HZ   = 20;            // log/telemetry rate
static const float    SEA_LEVEL_HPA_DEFAULT = 1013.25f;

// launch/apogee detection thresholds
static const float LAUNCH_ACCEL_G = 2.0f;   // > 2g => boost
static const float LAUNCH_ALT_M   = 3.0f;   // > 3m above ground => armed launch

// ---------------------------------------------------------------- globals
Adafruit_BMP280 bmp;              // I2C
Adafruit_MPU6050 mpu;            // I2C
TinyGPSPlus gps;
SPIClass sdSPI(FSPI);
WebServer server(80);

bool haveBMP = false;
bool haveMPU = false;
bool haveSD  = false;
File logFile;

float groundPressureHpa = SEA_LEVEL_HPA_DEFAULT;
float groundAltM        = 0.0f;
bool  launched          = false;
bool  deployed          = false;
uint32_t launchMs       = 0;

// latest telemetry (shared with web handlers)
struct Telemetry {
  float altM = 0;         // relative to ground
  float maxAltM = 0;      // apogee
  float tempC = 0;
  float ax = 0, ay = 0, az = 0;   // g
  float gx = 0, gy = 0, gz = 0;   // deg/s
  double lat = 0, lon = 0;
  float gpsAltM = 0;
  float speedKmh = 0;
  uint32_t sats = 0;
  bool gpsFix = false;
  uint32_t tMs = 0;
} tel;

// ---------------------------------------------------------------- helpers
// Active buzzer: drive low side (pin to GND side of buzzer)
static void buzzOn()  { digitalWrite(PIN_BUZZER, LOW); }
static void buzzOff() { digitalWrite(PIN_BUZZER, HIGH); }

static void beep(int n, int ms) {
  for (int i = 0; i < n; i++) { buzzOn(); delay(ms); buzzOff(); delay(ms); }
}

// Simple servo PWM on LEDC (ESP32-C3)
static const int SERVO_CH = 0;
static void servoWriteUs(int us) {
  // 50 Hz, 16-bit duty approx: duty = us / 20000 * 65535
  uint32_t duty = (uint32_t)((us / 20000.0f) * 65535.0f);
  ledcWrite(SERVO_CH, duty);
}
static void servoStow()    { servoWriteUs(1000); }  // ~0 deg — tune for your linkage
static void servoDeploy()  { servoWriteUs(2000); }  // ~180 deg — tune for nose release


// ---------------------------------------------------------------- web page
static const char INDEX_HTML[] PROGMEM = R"HTML(
<!doctype html><html><head><meta charset="utf-8">
<meta name="viewport" content="width=device-width,initial-scale=1">
<title>ArcTrack Live</title>
<style>
  body{font-family:system-ui,Arial,sans-serif;margin:0;background:#0b1020;color:#e7ecf5}
  header{padding:16px;background:#131a33;font-size:20px;font-weight:700}
  .grid{display:grid;grid-template-columns:1fr 1fr;gap:12px;padding:16px}
  .card{background:#151d3b;border-radius:14px;padding:16px}
  .k{font-size:12px;color:#8ea0c8;text-transform:uppercase;letter-spacing:.05em}
  .v{font-size:28px;font-weight:700;margin-top:4px}
  .full{grid-column:1/3}
  a.btn{display:inline-block;margin-top:10px;background:#3b6cff;color:#fff;
        padding:10px 14px;border-radius:10px;text-decoration:none;font-weight:600}
  .dot{height:10px;width:10px;border-radius:50%;display:inline-block;margin-right:6px}
  .ok{background:#2ecc71}.no{background:#e74c3c}
</style></head><body>
<header>&#128640; ArcTrack Live Tracking</header>
<div class="grid">
  <div class="card"><div class="k">Altitude (AGL)</div><div class="v" id="alt">--</div></div>
  <div class="card"><div class="k">Apogee</div><div class="v" id="max">--</div></div>
  <div class="card"><div class="k">Speed (GPS)</div><div class="v" id="spd">--</div></div>
  <div class="card"><div class="k">Temp</div><div class="v" id="tmp">--</div></div>
  <div class="card full"><div class="k">GPS <span id="fixdot" class="dot no"></span><span id="fix">no fix</span> &middot; sats <span id="sat">0</span></div>
    <div class="v" id="pos">--, --</div>
    <a class="btn" id="map" href="#" target="_blank">Open in Maps</a></div>
  <div class="card"><div class="k">Accel |a|</div><div class="v" id="acc">--</div></div>
  <div class="card"><div class="k">Status</div><div class="v" id="st">--</div></div>
</div>
<script>
async function tick(){
  try{
    const r = await fetch('/data'); const d = await r.json();
    alt.textContent = d.alt.toFixed(1)+' m';
    max.textContent = d.max.toFixed(1)+' m';
    spd.textContent = d.spd.toFixed(1)+' km/h';
    tmp.textContent = d.tmp.toFixed(1)+' \u00b0C';
    sat.textContent = d.sats;
    const amag = Math.sqrt(d.ax*d.ax+d.ay*d.ay+d.az*d.az);
    acc.textContent = amag.toFixed(2)+' g';
    st.textContent = d.launched ? 'IN FLIGHT' : 'armed';
    if(d.fix){
      fix.textContent='fix'; fixdot.className='dot ok';
      pos.textContent = d.lat.toFixed(6)+', '+d.lon.toFixed(6);
      map.href = 'https://maps.google.com/?q='+d.lat+','+d.lon;
    } else { fix.textContent='no fix'; fixdot.className='dot no'; }
  }catch(e){}
}
setInterval(tick, 500); tick();
</script></body></html>
)HTML";

static void handleRoot() { server.send_P(200, "text/html", INDEX_HTML); }

static void handleData() {
  char buf[420];
  snprintf(buf, sizeof(buf),
    "{\"t\":%lu,\"alt\":%.2f,\"max\":%.2f,\"tmp\":%.2f,"
    "\"ax\":%.3f,\"ay\":%.3f,\"az\":%.3f,"
    "\"lat\":%.6f,\"lon\":%.6f,\"gpsAlt\":%.1f,\"spd\":%.1f,"
    "\"sats\":%lu,\"fix\":%s,\"launched\":%s}",
    (unsigned long)tel.tMs, tel.altM, tel.maxAltM, tel.tempC,
    tel.ax, tel.ay, tel.az,
    tel.lat, tel.lon, tel.gpsAltM, tel.speedKmh,
    (unsigned long)tel.sats, tel.gpsFix ? "true" : "false",
    launched ? "true" : "false");
  server.send(200, "application/json", buf);
}

// ---------------------------------------------------------------- setup
static void initSensors() {
  Wire.begin(PIN_SDA, PIN_SCL);
  Wire.setClock(400000);

  if (bmp.begin(0x76) || bmp.begin(0x77)) {
    haveBMP = true;
    bmp.setSampling(Adafruit_BMP280::MODE_NORMAL,
                    Adafruit_BMP280::SAMPLING_X2,
                    Adafruit_BMP280::SAMPLING_X16,
                    Adafruit_BMP280::FILTER_X4,
                    Adafruit_BMP280::STANDBY_MS_1);
    Serial.println("BMP280 ok");
  } else Serial.println("BMP280 MISSING");

  if (mpu.begin(0x68)) {
    haveMPU = true;
    mpu.setAccelerometerRange(MPU6050_RANGE_16_G);
    mpu.setGyroRange(MPU6050_RANGE_2000_DEG);
    mpu.setFilterBandwidth(MPU6050_BAND_44_HZ);
    Serial.println("MPU6050 ok");
  } else Serial.println("MPU6050 MISSING");
}

static void calibrateGround() {
  if (!haveBMP) return;
  // average a second of readings to fix the ground reference
  double sum = 0; int n = 0;
  for (int i = 0; i < 50; i++) { sum += bmp.readPressure() / 100.0; n++; delay(20); }
  groundPressureHpa = (float)(sum / n);
  groundAltM = bmp.readAltitude(groundPressureHpa); // ~0
  Serial.printf("Ground ref: %.2f hPa\n", groundPressureHpa);
}

static void initSD() {
  sdSPI.begin(PIN_SD_SCK, PIN_SD_MISO, PIN_SD_MOSI, PIN_SD_CS);
  if (!SD.begin(PIN_SD_CS, sdSPI)) { Serial.println("SD MISSING"); return; }
  haveSD = true;

  // pick a new filename
  char name[20];
  for (int i = 0; i < 1000; i++) {
    snprintf(name, sizeof(name), "/flight%03d.csv", i);
    if (!SD.exists(name)) break;
  }
  logFile = SD.open(name, FILE_WRITE);
  if (logFile) {
    logFile.println("t_ms,alt_m,temp_c,ax,ay,az,gx,gy,gz,lat,lon,gps_alt,spd_kmh,sats,fix,launched");
    logFile.flush();
    Serial.printf("Logging to %s\n", name);
  } else { haveSD = false; Serial.println("SD open FAIL"); }
}

void setup() {
  pinMode(PIN_BUZZER, OUTPUT);
  buzzOff();
  ledcSetup(SERVO_CH, 50, 16);          // 50 Hz servo
  ledcAttachPin(PIN_SERVO, SERVO_CH);
  servoStow();

  Serial.begin(115200);
  delay(300);
  Serial.println("\nArcTrack boot");

  initSensors();
  calibrateGround();

  Serial1.begin(GPS_BAUD, SERIAL_8N1, PIN_GPS_RX, PIN_GPS_TX);

  initSD();

  WiFi.mode(WIFI_AP);
  WiFi.softAP(AP_SSID, AP_PASS);
  Serial.print("AP up: "); Serial.println(WiFi.softAPIP());
  server.on("/", handleRoot);
  server.on("/data", handleData);
  server.begin();

  beep(3, 120);
  Serial.println("ready");
}

// ---------------------------------------------------------------- loop
static void readGPS() {
  while (Serial1.available()) gps.encode(Serial1.read());
  if (gps.location.isValid()) {
    tel.lat = gps.location.lat();
    tel.lon = gps.location.lng();
    tel.gpsFix = true;
  }
  if (gps.altitude.isValid()) tel.gpsAltM = gps.altitude.meters();
  if (gps.speed.isValid())    tel.speedKmh = gps.speed.kmph();
  if (gps.satellites.isValid()) tel.sats = gps.satellites.value();
}

static void sampleSensors() {
  if (haveBMP) {
    tel.altM  = bmp.readAltitude(groundPressureHpa) - groundAltM;
    tel.tempC = bmp.readTemperature();
    if (tel.altM > tel.maxAltM) tel.maxAltM = tel.altM;
  }
  if (haveMPU) {
    sensors_event_t a, g, t;
    mpu.getEvent(&a, &g, &t);
    tel.ax = a.acceleration.x / 9.80665f;
    tel.ay = a.acceleration.y / 9.80665f;
    tel.az = a.acceleration.z / 9.80665f;
    tel.gx = g.gyro.x * 57.29578f;
    tel.gy = g.gyro.y * 57.29578f;
    tel.gz = g.gyro.z * 57.29578f;
  }
  tel.tMs = millis();
}

static void detectLaunch() {
  if (launched) return;
  float amag = sqrtf(tel.ax*tel.ax + tel.ay*tel.ay + tel.az*tel.az);
  if (amag > LAUNCH_ACCEL_G || tel.altM > LAUNCH_ALT_M) {
    launched = true;
    launchMs = millis();
    Serial.println(">>> LAUNCH detected");
    beep(1, 80);
  }
}

// Deploy once after apogee: altitude falls ~3 m from peak, and we've been flying a bit
static void detectApogeeDeploy() {
  if (!launched || deployed) return;
  if (millis() - launchMs < 800) return;          // ignore early noise
  if (tel.maxAltM < 5.0f) return;                 // need some altitude
  if (tel.altM < tel.maxAltM - 3.0f) {
    deployed = true;
    servoDeploy();
    beep(3, 100);
    Serial.println(">>> APOGEE deploy");
  }
}

static void logRow() {
  if (!haveSD || !logFile) return;
  logFile.printf("%lu,%.2f,%.2f,%.3f,%.3f,%.3f,%.2f,%.2f,%.2f,%.6f,%.6f,%.1f,%.1f,%lu,%d,%d\n",
    (unsigned long)tel.tMs, tel.altM, tel.tempC,
    tel.ax, tel.ay, tel.az, tel.gx, tel.gy, tel.gz,
    tel.lat, tel.lon, tel.gpsAltM, tel.speedKmh,
    (unsigned long)tel.sats, tel.gpsFix ? 1 : 0, launched ? 1 : 0);
}

void loop() {
  static uint32_t nextSample = 0;
  static uint32_t lastFlush  = 0;
  const uint32_t periodMs = 1000UL / SAMPLE_HZ;

  server.handleClient();
  readGPS();

  uint32_t now = millis();
  if (now >= nextSample) {
    nextSample = now + periodMs;
    sampleSensors();
    detectLaunch();
    detectApogeeDeploy();
    logRow();
  }

  // flush SD periodically (and faster during flight) so a crash keeps data
  uint32_t flushEvery = launched ? 500 : 2000;
  if (haveSD && logFile && now - lastFlush > flushEvery) {
    logFile.flush();
    lastFlush = now;
  }
}

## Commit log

2026-07-09 RocketFC: ESP32-C3 flight computer hardware design + firmware
2026-07-10 Publish ArcTrack v1.3: firmware, hardware docs, KiCad project, and Gerbers.
    Renames the project for the rocket flight computer with buzzer/servo support and JLCPCB fab outputs.
    [BOM_JLC.csv, PickPlace.csv, arctrack.kicad_pcb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]
